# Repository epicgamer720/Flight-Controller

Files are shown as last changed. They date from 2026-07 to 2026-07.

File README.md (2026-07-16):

# Rocket Flight Controller

A custom, open-source flight computer for model and high-power rockets, built around an STM32F722 with onboard IMU, barometer, GPS, pyro deployment, quad servo outputs, and microSD logging. Designed from scratch in KiCad.

## Why I built it

Wanted to get my feet wet with more mixed PCB design. I designed this as a base for firmware and testing I plan to designing another one after I build and test this one on actual rockets. I plan to use this for my rocketry team for active control and data logging 

## Use cases

- **Dual-deploy recovery**: pyro drogue at apogee, then a servo mechanically releases the main at a set altitude. (This rev routes one pyro channel; the servo is the second deploy.)
- **Active stabilization**: drive the four servo outputs for thrust-vector control or canard/fin steering during boost.
- **Flight data logging**: log IMU, barometer, and GPS to microSD for post-flight analysis (apogee, max velocity, flight path).
- **GPS tracking**: downrange tracking and finding the rocket after landing.
- **Telemetry**: LoRa (SX1262, 915 MHz) for live altitude/position downlink.
- **General avionics dev board**: the IMU + baro + GPS + servo + logging combo also works for drones, RC, robotics, or balloon payloads.





## Specifications

| Subsystem | Part / detail |
|---|---|
| MCU | STM32F722RET6, Cortex-M7, up to 216 MHz |
| IMU | ISM330DHCX, 6-axis accel (±16 g) + gyro, SPI (built rev; early docs said ICM-45686) |
| Barometer | BMP580, altitude / apogee detection (I²C) |
| Storage | microSD (SDMMC1, 4-bit), 200 Hz binary flight log |
| Recovery | 1 pyro channel (gate PB13, continuity sense PC1) + servo main-release, giving dual-deploy without a 2nd pyro (2 designed) |
| Control | 4× servo outputs (TIM2) for TVC / fin / canard; one doubles as the main-release |
| GPS | NMEA module on USART6, JST-GH + PRTR5V0U2X ESD protection |
| Telemetry | LoRa Wio-SX1262 (915 MHz, TCXO): live downlink + over-air TX-power control, verified on hardware |
| Power | 2S LiPo, BQ25883 charger, USB-C |
| Status | WS2812 RGB status LED |

## Bench status (July 2026)

All subsystems green on hardware: IMU, barometer, SD logging, LoRa radio
(TCXO confirmed, telemetry transmitting), charger, GPS UART. The firmware
builds with `arm-none-eabi-gcc` (GitHub CI), has been flashed to the board,
and passes its on-console **preflight** GO/NO-GO check, so it is **bench-verified,
not flight-tested**. The deploy-critical logic is exercised host-side by a SIL
harness (a faithful Python transcription of the state machine / Kalman / pyro
paths) plus 245 stdlib-`unittest` tests, and went through several adversarial
multi-agent review passes.

Flight hardening on top of the earlier IWDG watchdog + reset-cause logging,
Kalman altitude filter with outlier gating, and pad-drift baro tracking:

- **Hardened arm gate**: refuses to arm without pyro continuity, adequate
  battery, near-zero velocity, *and* a plausible skyward orientation
  (`ARM_UP_AXIS`).
- **Fault-independent backup deploy**: a backup timer fires the charge even
  through `ST_FAULT` with dead sensors, so a sensor loss isn't a lawn-dart.
- **Servo dual-deploy**: a main-release servo held SAFE through ascent,
  actuated at the main-deploy altitude (no 2nd pyro needed).
- **Flash config v2**: runtime-tunable apogee/backup timer + last-GPS-for-
  recovery, migrating cleanly from v1.
- **Telemetry v3**: sequence / packet-delivery ratio, last-event echo,
  main-alt read-back, STM32 die-temp, and over-air TX-power control.
- Gyro-cal stationarity check, IMU-freeze detection, self-healing ground
  FAULT, failed-deploy detection, deeper anti-replay nonce window, baro
  temperature compensation, a recovery LED strobe (WS2812), and a STOP-mode
  low-power `sleep`.

**Tune before flight**: the defaults are placeholders, not final: `ARM_UP_AXIS`
(confirm the skyward IMU axis), the apogee/backup timer per motor (`apogee`
console cmd), the servo endpoints, and the flight thresholds (`LAUNCH_G`,
`MAIN_ALT`, debounces). The baro-only Kalman also lags true apogee by ~70 m in
SIL at `KAL_Q_ACCEL=4`, a candidate to raise once real flight data exists.
Also remaining: ground-station pin map + build, and a healthier USB cable.

## BOM

| Name | Purpose | Qty | Unit Cost (USD) | Line Cost (USD) | Link | Distributor | Notes |
|---|---|---|---|---|---|---|---|
| 1uF | Decoupling cap (0603, X7R, 25V) | 4 | $0.02 | $0.08 | Link | Digikey | |
| 10uF | Bulk decoupling (0805, X5R, 16V) | 7 | $0.10 | $0.40 | Link | Digikey | |
| 47nF | Filter cap, possibly BQ25883 ILIM or feedback (0603) | 1 | $0.02 | $0.02 | Link | Digikey | |
| 44uF | Unusual value, check schematic | 1 | $0.50 | $0.50 | Link | Digikey |  |
| 10uF | Bulk decoupling (0805, X5R) | 2 | $0.10 | $0.20 | Link | Digikey | |
| 22uF | Switching regulator output cap (0805, X5R, 16V) | 3 | $0.20 | $0.60 | Link | Digikey | |
| 100nF | Generic decoupling, 0402 or 0603 X7R | 12 | $0.01 | $0.12 | Link | Digikey | |
| 2.2uF | STM32 VCAP_1 (PA0) capacitor, 2.2µF X7R 0603 | 1 | $0.05 | $0.05 | Link | Digikey | Critical for MCU core regulator stability |
| 22uF | Regulator input/output cap | 2 | $0.20 | $0.40 | Link | Digikey | |
| 2.2uF | Second VCAP or filter | 1 | $0.05 | $0.05 | Link | Digikey | |
| 20pF | HSE crystal load capacitor (matches X322525MOB4SI) | 2 | $0.05 | $0.10 | Link | Digikey | Value depends on crystal CL spec, verify |
| 6.8pF | LSE 32.768kHz crystal load capacitor | 2 | $0.05 | $0.10 | Link | Digikey | Adjust to match crystal CL = ~7pF |
| 100nF | Generic decoupling, 0402 or 0603 | 5 | $0.01 | $0.05 | Link | Digikey | |
| TF-01A | MicroSD card socket (push-pull or hinged) | 1 | $1.50 | $1.50 | Link | LCSC | LCSC-style part; Hirose DM3AT-SF-PEJM5 is a Digikey alternative |
| LED | Generic indicator LED 0603 (e.g., power indicator) | 1 | $0.10 | $0.10 | Link | Digikey | |
| WS2812B-2020 | Addressable RGB status LED, single-wire (KMK-style) | 1 | $0.30 | $0.30 | Link | LCSC | Cheaper on LCSC than Digikey |
| PRTR5V0U2X | Dual-line TVS ESD protection for GPS UART | 1 | $0.35 | $0.35 | Link | Digikey | Nexperia, SOT-143B |
| Screw_Terminal_01x02 | 2-pin screw terminal for pyro outputs and battery | 3 | $1.20 | $3.60 | Link | Digikey | |
| BM05B-GHS-TBT_LF__SN__N_ | JST-GH 5-pin top-entry connector (GPS, Pixhawk standard) | 1 | $0.55 | $0.55 | Link | Digikey | JST part #BM05B-GHS-TBT(LF)(SN)(N) |
| FCM1608KF-601T03 | Ferrite bead 600Ω @ 100MHz, 0603, analog supply filter | 1 | $0.10 | $0.10 | Link | Digikey | Taiyo Yuden |
| DFE252012F-1R0M=P2 | Power inductor 1.0µH, 2520 case, buck output (LMR51430?) | 1 | $0.40 | $0.40 | Link | Digikey | Toko/Murata, ~3.6A saturation |
| XFL4020-152MEC | Power inductor 1.5µH, 4×4mm, switcher output | 1 | $1.50 | $1.50 | Link | Digikey | Coilcraft, very low DCR |
| YHNR3015-5R6M | Power inductor 5.6µH, likely buck-boost (TPS63070) | 1 | $0.30 | $0.30 | Link | LCSC | Sunlord, LCSC-stocked |
| AO3400A | N-channel logic-level MOSFET, SOT-23, pyro low-side switch | 2 | $0.15 | $0.30 | Link | Digikey | |
| 5.1K Ohm | Pullup/divider for USB-C CC1/CC2 (5.1k for device-mode detect) | 2 | $0.01 | $0.02 | Link | Digikey | Required for USB-C device mode |
| .383k Ohm | Precision resistor, likely BQ25883 ISET or regulator FB | 1 | $0.10 | $0.10 | Link | Digikey | |
| 5.23K Ohm | Feedback divider for switching regulator | 1 | $0.05 | $0.05 | Link | Digikey | 1% precision |
| 30.1K Ohm | Feedback divider (top resistor) for switching regulator | 1 | $0.05 | $0.05 | Link | Digikey | 1% precision |
| 10K Ohm | Generic pullups/pulldowns, gate pulldowns on MOSFETs (0603) | 19 | $0.01 | $0.19 | Link | Digikey | Cheap in bulk |
| 100K Ohm | Continuity divider top (pyro sense) | 1 | $0.01 | $0.01 | Link | Digikey | |
| 22.1K Ohm | Precision feedback or current-set resistor | 1 | $0.05 | $0.05 | Link | Digikey | 1% precision |
| 100K Ohm | More continuity dividers | 2 | $0.01 | $0.02 | Link | Digikey | |
| 100 Ohm | Gate series resistors on pyro MOSFETs | 3 | $0.01 | $0.03 | Link | Digikey | |
| Conn_01x03 | 3-pin header, likely servo/PWM outputs or programming | 4 | $0.30 | $1.20 | Link | Digikey | (2.54mm standard) |
| TS-1088-AR02016 | Tactile switch for boot/reset buttons | 2 | $0.20 | $0.40 | Link | Digikey | Cheap SMD tactile, also on LCSC |
| STM32F722RETx | Main MCU, ARM Cortex-M7, 216MHz, 512KB flash | 1 | $10.50 | $10.50 | Link | Digikey/Mouser | Check stock: F7 series can be supply-constrained |
| BQ25883RGER | Single-cell Li-ion charger w/ I2C, up to 2A | 1 | $3.80 | $3.80 | Link | Digikey | TI, QFN-24 |
| ICM-45686 | 6-axis IMU (accel + gyro), low-noise, SPI | 1 | $12.00 | $12.00 | Link | Digikey | TDK InvenSense, LGA-14. Newer than ICM-42688-P |
| BMP580 | Barometric pressure / altitude sensor (high resolution) | 1 | $4.20 | $4.20 | Link | Digikey | Bosch Sensortec, replaces BMP388 |
| TPS63070RNMR | Buck-boost regulator, 2A, 2-16V in | 1 | $3.60 | $3.60 | Link | Digikey | TI, VQFN-15 |
| LMR51430 | Buck regulator, 3A, simple step-down | 1 | $1.40 | $1.40 | Link | Digikey | TI, SOT-23-6 family |
| TYPE-C 16PIN 2MD(073) | USB-C connector, 16-pin (USB 2.0 only) | 1 | $0.50 | $0.50 | Link | LCSC | LCSC-style part number. Alt: GCT USB4105-GF-A (Digikey) |
| X322525MOB4SI | HSE crystal 25MHz, SMD 3225 | 1 | $0.60 | $0.60 | Link | LCSC | Yangxing. Alt: Abracon ABM8G-25.000MHZ |
| Q13FC1350000400 | LSE crystal 32.768kHz (RTC) | 1 | $0.40 | $0.40 | Link | Digikey | Epson FC-135 |

## Firmware & software

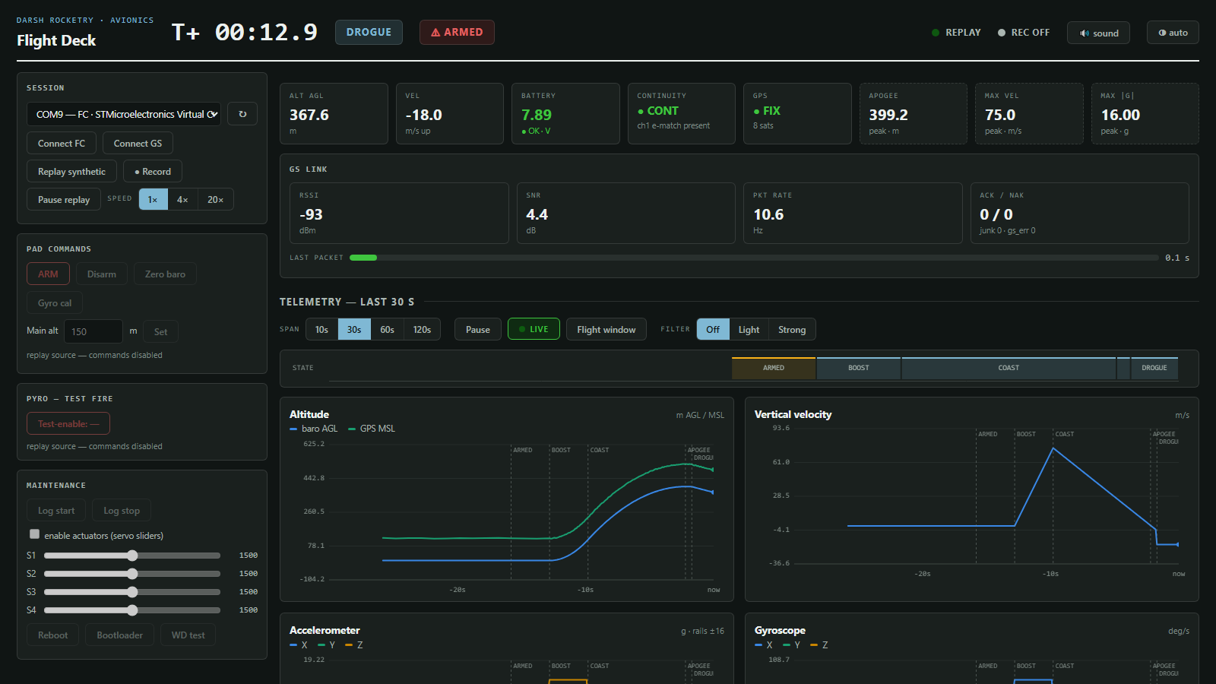
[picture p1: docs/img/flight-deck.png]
Flight Deck, the offline flight-ops dashboard, mid-flight on the synthetic profile


The flight firmware and ground tools live in this repo:

| Where | What |
|---|---|
| [`flight-controller/`](flight-controller/) | STM32F722 flight firmware: sensors, Kalman altitude filter, flight state machine, hardened arm gate + interlocked pyro control, fault-independent backup deploy, servo main-release, flash config v2, SD logging, LoRa telemetry v3 (die-temp + TX-power control), IWDG watchdog, USB console (`preflight`, `apogee`, `sleep`, …) |
| [`ground-station/`](ground-station/) | RP2040 + SX1262 LoRa ground station (RadioLib sketch; pin map pending) |
| [`shared/`](shared/) | `protocol.h`, the single source of truth for the radio link + packet formats |
| [`tools/`](tools/) | **Flight Deck** ops dashboard (recovery bearing/distance, baro-vs-GPS apogee check, telemetry-loss alarm, satellite GPS ground-track, SD `.bin` replay), one-page flight report, DFU flash helper (`flash.py`), serial monitor, log/telemetry decoders (`decode_log.py --summary`) |
| [`tests/`](tests/) | 245 host-side unit tests + a SIL flight harness (`py -m unittest discover -s tests`) |
| [`docs/FIRMWARE.md`](docs/FIRMWARE.md) | build / flash / console / bench guide |
| [`docs/PINMAP.md`](docs/PINMAP.md) | authoritative pin map extracted from the KiCad netlist |

## This project uses:

- [KiCad](https://www.kicad.org/)
- [STM32CubeMX](https://www.st.com/en/development-tools/stm32cubemx.html)
- [easyeda2kicad.py](https://github.com/uPesy/easyeda2kicad.py)
- [Hack Club Blueprint](https://blueprint.hackclub.com/)

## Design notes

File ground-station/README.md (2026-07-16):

# Ground Station (RP2040 + SX1262 + PE4259)

Compile-only skeleton of the ground-station firmware (CLAUDE.md §6):

- **RX**: IRQ-driven (DIO1) continuous LoRa receive of FC packets; each frame is
  validated (magic / version / CRC16-CCITT) and emitted as **one line of JSON**
  on USB-CDC Serial. Field names match `tools/telem_decode.py parse_telem()`
  output, plus `rssi` / `snr` from RadioLib.
- **TX**: operator commands typed on the same serial port become
  `command_packet_t` uplinks with a monotonically increasing, random-start
  nonce. Pad-only enforcement stays on the FC; the GS just sends.
- Link params and packet structs come **directly from `shared/protocol.h`**
  (single source of truth, §3/§7) via a `-I<repo>/shared` include flag.

```
ground-station/
  gs/
    gs.ino       sketch (Arduino-Pico + RadioLib)
    gs_pins.h    pin map: ALL -1 SENTINELS until extracted from the schematic
  README.md      this file
```

## 1. Install the toolchain

```sh
# arduino-cli: https://arduino.github.io/arduino-cli/latest/installation/
#   Windows: download the .zip, put arduino-cli.exe on PATH
#   (or: winget install ArduinoSA.CLI)

arduino-cli config init
arduino-cli config add board_manager.additional_urls \
  https://github.com/earlephilhower/arduino-pico/releases/download/global/package_rp2040_index.json
arduino-cli core update-index
arduino-cli core install rp2040:rp2040     # Earle Philhower Arduino-Pico core
arduino-cli lib install RadioLib           # SX1262 driver (6.x/7.x API used)
```

## 2. Compile

Run from the repo root (`C:\Users\14437\OneDrive\Desktop\flight controller`).
The repo path contains a **space**, so the `-I` flag needs quoting at *two*
levels: your shell must hand arduino-cli the literal value

```
compiler.cpp.extra_flags=-I"C:/Users/14437/OneDrive/Desktop/flight controller/shared"
```

as **one argument with the inner double quotes intact**, because arduino-cli splits
the expanded compiler recipe on spaces *except inside double quotes*, so the
inner quotes are what keep the path together as a single `-I` argument to gcc.
(Use forward slashes: a trailing `shared\"` backslash would escape the quote.)

**Git Bash** (`\` line continuations are bash-only; for cmd.exe use `^` or put
it all on one line):

```sh
arduino-cli compile -b rp2040:rp2040:rpipico --warnings default \
  --build-property "compiler.cpp.extra_flags=-I\"C:/Users/14437/OneDrive/Desktop/flight controller/shared\"" \
  --output-dir ground-station/gs/build \
  ground-station/gs
```

**PowerShell 5.1** (does *not* escape embedded quotes for native commands, so
they must be backslash-escaped manually even inside single quotes):

```powershell
arduino-cli compile -b rp2040:rp2040:rpipico --warnings default `
  --build-property 'compiler.cpp.extra_flags=-I\"C:/Users/14437/OneDrive/Desktop/flight controller/shared\"' `
  --output-dir ground-station\gs\build `
  ground-station\gs
```

> `--warnings default` matters: arduino-cli's default warning level is `none`,
> which compiles with `-w` and **silently suppresses the intentional
> `#warning`** in `gs_pins.h`. Without it the only pin-sentinel guard you'll
> see is the runtime `{"error": ...}` refusal on the serial port.

> Quoting rationale worked out from arduino-cli's recipe splitter + PS 5.1
> native-argument rules; **not yet verified by an actual compile**, since arduino-cli
> was not installed on this machine when the skeleton was written. If the build
> fails with `cannot find protocol.h` or gcc sees `controller/shared"` as an
> input file, the quoting was mangled by the shell; try the other shell's form.

**Expected output**: the build **succeeds** but prints

```
warning: gs_pins.h: pin map not yet extracted from the GS KiCad schematic ...
```

That `#warning` is intentional (see §5) and stays until `gs_pins.h` is filled in.

## 3. Flash

**BOOTSEL (no tools needed):** hold the BOOTSEL button while plugging in USB;
a `RPI-RP2` drive appears; copy `ground-station/gs/build/gs.ino.uf2` onto it.
The board reboots into the firmware.

**picotool:**

```sh
picotool load -f ground-station/gs/build/gs.ino.uf2
picotool reboot
```

## 4. Use

Open the USB-CDC serial port (any baud; e.g. 115200). Output is line-delimited
JSON: one object per received packet (telemetry / event / ack, keyed by
`type`), or `{"error": ...}` lines for CRC/length failures and status.

Commands (one per line, newline-terminated):

| Command | Uplink | `arg` encoding | FC-side gate |
|---|---|---|---|
| `arm` | CMD_ARM | 0 | pad + sensors healthy |
| `disarm` | CMD_DISARM | 0 | none |
| `mainalt <m>` | CMD_SET_MAIN_ALT | meters × 100 (cm), 30–2000 m | refused while armed; persisted to flash |
| `zero` | CMD_ZERO_BARO | 0 | pad only |
| `reboot` | CMD_REBOOT | 0 | none |
| `fire <ch> <hexcode>` | CMD_TEST_FIRE | `passcode<<16 \| channel` | ST_GROUND_IDLE + disarmed + `testen` + passcode + fresh nonce |
| `nop` | CMD_NOP | 0 | none |
| `help` | (local) | none | none |

Each uplink is transmitted **once** and reported as an `{"uplink": ...}` JSON
line with the nonce and RadioLib TX status; the FC's ACK (a 46-byte frame with
`type` = 0x11) shows up as a normal JSON line when it arrives. Uplinks only
land while the FC is on the pad. In flight the FC is TX-only (§4) and the
command is simply lost (resend from the pad).

## 5. What is blocked, and how to unblock

Hardware bring-up is **blocked** on two things (compile is not):

1. **GS pin map extraction**: every pin in `gs/gs_pins.h` is a `-1` sentinel.
   Per CLAUDE.md §0 the KiCad schematic is the source of truth and GPIO numbers
   must never be guessed. *Unblock*: parse the GS `.kicad_sch` / netlist,
   fill in NSS / DIO1 / NRESET / BUSY / SCK / MOSI / MISO (RP2040 GPIO
   numbers), confirm the pins land on one SPI block (`SPI` vs `SPI1`, see the
   comment in `gs_pins.h`), and set `GS_RADIO_TCXO` (0 = XTAL, 1 = TCXO via
   DIO3) from the schematic; the current 0 is a placeholder, not an answer.
   Rebuild; the `#warning` disappears and the runtime refusal loop lifts.
2. **FC radio hardware**: the flight controller currently reports `radio=0`
   on the bench (see `radiodbg` console triage). Until the FC's SX1262
   transmits, the GS has nothing to receive. *Unblock*: fix/verify the FC
   radio, then confirm the link with the FC on pad cadence (1 Hz).

Also before range tests: verify +22 dBm at 915 MHz against regulatory limits
(CLAUDE.md §10).

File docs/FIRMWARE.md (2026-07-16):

# Rocketry Avionics: bench quickstart

Flight controller firmware for an **STM32F722RET6** board (`flight-controller/`) plus a
planned **RP2040 ground station**, linked over **915 MHz LoRa** (SX1262 on both ends).
`shared/protocol.h` is the wire contract for both boards; `CLAUDE.md` has the full
design context and safety rules; `docs/PINMAP.md` is the authoritative pin map.

> **Status:** SIL/host-tested, builds clean, and flashed + bench-verified on hardware,
> but **not yet flight-tested.** Flight thresholds in `App/app_config.h` are still defaults;
> tune them (and the mount knobs flagged below) to the motor/airframe before flying.

## Build

No SWD on this board, so everything goes through USB (CDC console + DFU flashing).

```
cd flight-controller
C:/Users/14437/toolchains/build-tools/bin/make.exe -j GCC_PATH=C:/Users/14437/toolchains/arm-gcc/bin
```

Outputs `build/fc.elf`, `build/fc.hex`, `build/fc.bin`.

## Flash (USB DFU)

1. Enter the bootloader: type `bootloader` on the console, **or** hold BOOT (SW2),
   tap RESET (SW1), release BOOT.
2. Flash:

```
dfu-util -l                                              # should list 0483:df11
dfu-util -a 0 -d 0483:df11 -s 0x08000000:leave -D build/fc.bin
```

If dfu-util says **"cannot open"**: unplug USB and replug it *while holding BOOT*.
(`STM32_Programmer_CLI -c port=usb1 -w build\fc.bin 0x08000000 -v -g 0x08000000`
works too; see `docs/PINMAP.md`.)

## Console commands

115200-8N1 USB-CDC (baud ignored). The authoritative list is `help` on the board
(`App/console.c`, `cmd_help`); snapshot:

| Command | Does |
|---|---|
| `help` | command list |
| `status` | state / armed / alt / vel / batt / **MCU die-temp** / flags / health / pyro |
| `preflight` | GO/NO-GO checklist before arming (read-only, nothing is pulsed) |
| `sensors` | raw IMU + baro |
| `gps` | last GPS fix + persisted last-landing fix |
| `servo <1-4> <500-2500>` | set servo pulse (µs) |
| `arm` / `disarm` | arming gate (prints refusal code `-1`..`-8`) / disarm |
| `testen <on\|off>` | pad test mode (GROUND_IDLE only; always boots **off**) |
| `fire <ch> <hex-code>` | pad test fire (testen + passcode gated) |
| `zero` | zero baro AGL |
| `mainalt <m>` | set main deploy altitude (persisted to flash) |
| `apogee <ms>` | set apogee / backup-deploy timer (per-motor); persisted to flash |
| `log <stat\|start\|stop>` | SD logging (stat shows drops + ring high-water) |
| `cal` | pad gyro bias cal (~2 s, keep still; rejected if it moves) |
| `radio` | radio health + re-init / TX-timeout counters |
| `radiodbg` | raw SX1262 hardware probe (BUSY/reset/SPI bytes) |
| `tx [power\|mon\|cw\|frame]` | TX dashboard; set power / packet monitor / bench CW / force a frame |
| `i2cscan` | scan I2C1 for devices |
| `charge` | BQ25883 charger status |
| `bootloader` | reboot into USB DFU |
| `reboot` | reset MCU |
| `wdtest` | deliberate hang; IWDG must reset the board in ~4 s |
| `sleep [s]` | STOP-mode low power (ground + disarmed); wakes on RTC timer or RESET; 0/none = until RESET |

## Tools (`tools/`)

`py -m pip install -r requirements.txt` (pyserial for the serial tools, pywebview for Flight Deck's native window).

| Tool | Use |
|---|---|
| `py tools/flight_deck.py` | **Flight Deck**, the flight-ops dashboard (see below) |
| `py tools/serial_monitor.py` | timestamped console; auto-detects the FC COM port (`--list`, `--port COM7`) |
| `py tools/live_dashboard.py [--port COM9] [--http 8321]` | simple bring-up charts at http://localhost:8321. **Owns the COM port while running**, so stop it before serial_monitor or flashing |
| `py tools/decode_log.py LOG001.BIN [out.csv]` | SD binary log → CSV (68-B records, CRC-checked, resyncs past corruption) |
| `py tools/telem_decode.py <hex>` | parse/build LoRa packets from `shared/protocol.h`; importable by the GS bridge |

## Flight Deck (`tools/flight_deck.py`)

Offline mission-control app in a native window (pywebview/WebView2; `--browser`
falls back to the default browser). Fully local: 127.0.0.1 only.

```
py tools/flight_deck.py                          # FC over USB, auto-detects the port
py tools/flight_deck.py --source gs --port COM7  # ground-station JSON bridge
py tools/flight_deck.py --source replay --synthetic --speed 4   # no hardware needed
py tools/flight_deck.py --source replay --replay recordings/deck_.../raw.jsonl
```

- **Instruments**: T+ clock (starts at BOOST), state timeline, alt/vel/accel/
  gyro/battery charts with labeled event markers + pan/zoom/pause + flight-window
  button, peak tiles (apogee, max vel, max |g|), continuity/battery/GPS tiles,
  GS link panel (RSSI/SNR/packet rate/gap/ACK-NAK), scrolling event log with
  verbatim firmware refusals, audio alerts (state, FAULT, low battery), theme
  toggle.
- **Commands** are interlocked in the UI *and* re-checked by the firmware (the
  firmware is always the real gate): arm/disarm confirmations, mainalt bounded
  30–2000 m (the radio path's stricter bound), test-fire behind test-enable →
  passcode (never stored, never logged; masked even in recordings) → 2 s
  hold-to-fire. In flight the FC is TX-only, so every command control disables
  itself with the reason shown.
- **Recording**: each live session writes `recordings/deck_<stamp>/telem.csv` +
  `events.csv` (+ lossless `raw.jsonl` on GS sessions); replay any of them with
  `--source replay --replay <file>`. FC sessions are poll-rate on the ground;
  the FC's own 200 Hz SD log remains the authoritative flight record.
- **Owns its COM port** while running (like live_dashboard). It closes the port
  on every exit path; if a hard-killed host process ever wedges the FC's USB
  console (port opens but no replies), tap RESET or replug USB.

## Tests

```
py -m unittest discover -s tests
```

Stdlib-only: CRC16 golden vectors, log-record decode/resync, telemetry packet
round-trips, a Python port of the Kalman gate, and a console↔dashboard contract
test that fails loudly if `App/console.c` output drifts from what
`tools/live_dashboard.py` scrapes.

## BOR option byte (one-time, manual)

```
# board in DFU mode first (BOOT + RESET)
STM32_Programmer_CLI -c port=usb1 -ob displ          # check current BOR_LEV first
STM32_Programmer_CLI -c port=usb1 -ob BOR_LEV=0      # 0b00 = BOR Level 3 ≈ 2.7 V
```

Sets brown-out reset to ~2.7 V. **The F7 encoding is inverted-looking** (RM0431,
FLASH_OPTCR bits 3:2): value **0 = Level 3 (~2.7 V)** … value **3 = BOR off**,
which is also the shipping default, so a fresh chip displays `BOR_LEV: 0x3`.
Without it, a battery sag or pyro-fire droop can leave the F7 running erratically
(corrupting flash/SD writes) instead of resetting cleanly. Option bytes live
outside program flash, so this survives reflashing; do it once per board.

## Safety & flight logic

Every pyro decision is made in `App/state_machine.c` and only there: radio commands can
never fire in flight (CLAUDE.md §2). Not flight-tested yet; the thresholds are defaults.

- **Arming gate** (`fsm_request_arm`) requires *all* of: `ST_GROUND_IDLE`, IMU + baro
  healthy, gyro cal done, near-zero velocity, plausible |accel|, **pyro continuity**,
  **battery ≥ `ARM_MIN_VBAT_MV` (7.0 V)**, and **vertical orientation**. On refusal it
  returns a code the console prints in English: `-1` not idle, `-2` imu/baro, `-3` gyro
  cal, `-4` moving, `-5` accel implausible, `-6` no pyro continuity, `-7` battery low,
  `-8` not vertical. Orientation keys off `ARM_UP_AXIS`/`ARM_UP_SIGN` (default +Z, a
  **mount knob**); a wrong axis safely *refuses* with `-8`, it never misfires. `preflight`
  shows the same checks as a GO/NO-GO list without arming.
- **Fault-independent backup deploy**: once launched, the single charge fires at
  `apogee_timeout_ms` after launch **even in `ST_FAULT`** with dead sensors: it bypasses
  the armed gate through one controlled path (`pyro_fire_backup`). Fires at most once,
  never on the pad and never after landing; a deploy pulse is aborted **only** by a ground
  disarm, never truncated by an in-flight fault. This is the anti-lawn-dart last line; set
  `apogee` to just past expected apogee per motor (clamped to `[MAX_BURN_MS, 120000]` so it
  can't fire under thrust).
- **Servo main-release** (this board has one pyro channel, fired at apogee; a servo releases
  the main): held SAFE through all ascent and through `ST_FAULT`, released only at the guarded
  DROGUE→MAIN point (descending AND AGL ≤ `main_alt`, upward velocity inhibited). Parked SAFE
  at boot before the first control pass. `SERVO_SAFE_US`/`SERVO_RELEASE_US` are **mount knobs**.
- **Sensor guards**: gyro cal is rejected if the vehicle moves during it (per-axis gyro
  peak-to-peak + accel-stray band → auto-restart, so a bad bias never latches); IMU reads
  detect a frozen/stuck bus (rail bytes, or N byte-identical bursts) and fail, tripping the
  0.5 s IMU-fail debounce → `ST_FAULT`; baro altitude is temperature-compensated (pad temp
  latched at `zero`).
- **Fault handling**: a *ground* fault (never launched) self-heals back to `ST_INIT` once
  both sensors read healthy again (re-runs gyro cal + baro zero); any *in-flight* fault
  latches: logging + telemetry keep running, pyros safe, the backup timer still armed.
- **Anti-replay**: 32-deep nonce dedup ring with **no** monotonic floor. The GS reseeds its
  nonce randomly on restart, so a floor would permanently lock out a restarted GS.

## Firmware notes

- **IWDG ~4 s** is armed at the end of init and refreshed once per superloop pass;
  any hang reboots the MCU (reset cause is printed in the boot banner). `wdtest`
  proves it end-to-end.
- **Config persists** in flash **sector 7 @ `0x08060000`** (append-record store **v2**,
  `App/param_store.c`): 28-byte slots holding `main_alt`, the runtime `apogee_timeout`,
  and the last landing GPS fix (recovery aid). Migrates cleanly from the old 16-byte v1
  (mismatched records are skipped, then appended past). Code flash is capped at **384 KB**
  in the linker so an oversized image fails at link instead of clobbering the store.
  **Never persisted** by design: `testen` (boots off), gyro bias, baro zero; all re-done
  each pad session.
- **Telemetry is protocol v3** (`PROTO_VERSION 3`, 54-byte `telem_packet_t` in
  `shared/protocol.h`): per-frame `seq` (host computes packet-delivery ratio), a last-event
  echo (`last_evt_state` + `last_evt_count`, so a dropped `PKT_EVENT` still surfaces), and a
  `main_alt` read-back; plus `FLAG_LOW_BATT` and `FLAG_DEPLOY_FAIL` status bits. FC and GS
  must compile the same `protocol.h`. `CMD_SET_TX_POWER` sets TX power over the air (pad-only,
  like every uplink command).
- **64 KB SD log ring** (~4.8 s of 200 Hz records); `log stat` reports drops and
  ring high-water.
- `log start` failure codes: `-1` no card, `-2` link, `-3` mount, `-4` scan,
  `-5` slots, `-6`/`-7` open.

## Status LED legend (WS2812 on PC13, needs the 5 V rail)

| State | Color |
|---|---|
| INIT | dim white |
| GROUND_IDLE | rainbow cycle with GPS fix, dim green without; red if armed |
| ARMED | solid red |
| BOOST / COAST | magenta |
| APOGEE / DROGUE | cyan |
| MAIN / DESCENT | amber |
| LANDED | bright green recovery strobe (~1/s) |
| FAULT | bright red recovery strobe (~1/s) |
| SD not logging | blue flash once per second (overlays any state) |

Bench test (console, pad + disarmed only): `led <r> <g> <b>` shows a raw
color for 5 s; `led bright <0-100>` sets a global brightness scale (all
patterns, persists until reboot); `led cycle [period_ms]` steps through
every flight state so you can preview the mapping above; `led state
<name|0-10>` holds on one specific state's pattern (e.g. `led state
LANDED`); `led effect solid|blink|breathe|strobe <r> <g> <b> [period_ms]`
and `led effect rainbow [period_ms]` run a bench-only pattern; `led auto`
/ `led effect off` resumes the real flight-state pattern. Arming
force-clears any active test/effect so it can never mask the ARMED
indicator. Flight Deck (`tools/flight_deck.py`) exposes all of these as
a Status LED bench panel when connected over USB.

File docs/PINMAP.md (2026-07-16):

# Flight Controller pin map (authoritative)

Source: `C:\Users\14437\Downloads\fe\Flight controler.kicad_sch`, netlist exported
2026-07-07 with `kicad-cli sch export netlist --format kicadxml`. This resolves all
`TODO` rows in CLAUDE.md §5.2. The board's IMU is **ISM330DHCX** (matches CLAUDE.md;
the December 2025 board rev in `Desktop\Flight-Controller` used ICM-45686 + no radio;
that rev is obsolete).

| Function | Pin | Notes |
|---|---|---|
| IMU ISM330DHCX CS | PA4 | 10K pull-up (R23) |
| SPI1 SCK / MISO / MOSI | PA5 / PA6 / PA7 | shared IMU + LoRa, mode 0, 6.75 MHz |
| IMU INT1 / INT2 | PC4 / PB0 | inputs (polled) |
| LoRa Wio-SX1262 CS | PA9 | 10K pull-up (R24) |
| LoRa DIO1 (IRQ) | PA10 | EXTI15_10, rising |
| LoRa BUSY | PB1 | input |
| LoRa NRESET | PA15 | output, active low |
| LoRa RF_SW1 | PB2 | **keep high-Z (analog)**, driven by module DIO2 |
| Barometer BMP580 | I2C1 PB6/PB7 | 4.7K pull-ups; INT = PB9; addr 0x46/0x47 |
| Charger BQ25883 | I2C1 PB6/PB7 | addr 0x6B; INT = PB5 (10K PU); ~CE = PB8 (low = charge) |
| GPS (JST-GH J8) | USART6 TX=PC6 RX=PC7 | PPS = PA8; ESD PRTR5V0U2X; ext. module |
| Pyro 1 gate | **PB13** | AO3400A low-side (Q2); 100R gate R, 10K pulldown; **boot LOW** |
| Pyro 1 continuity | **PC1** = ADC123_IN11 | divider 100K(R29)/10K(R30) from J7.2; VBAT/11 when continuous |
| Pyro terminal | J7 | J7.1 = BAT+, J7.2 = FET drain |
| (dangling) | PC0 | schematic label `PYRO_CON_1` unrouted, unused |
| Servo 1–4 | PA0/PA1/PA2/PA3 | TIM2 CH1–4, AF1, 50 Hz |
| SD card | SDMMC1 4-bit | D0=PC8 D1=PC9 D2=PC10 D3=PC11 CLK=PC12 CMD=PD2 (all 10K PU) |
| SD card detect | PB3 | internal pull-up, LOW = card present |
| USB-C | PA11=DM PA12=DP | device (5.1K CC pulldowns); **PA9 VBUS sensing OFF** (PA9 = LoRa CS!) |
| Status LED WS2812B-2020 | PC13 | via 100R; PC13 is low-drive, so it's bit-banged, best-effort |
| Buttons | SW1=NRST, SW2=BOOT0 | BOOT0 + reset = USB DFU bootloader |
| HSE / LSE | PH0/PH1 25 MHz, PC14/PC15 32.768 kHz | |
| Battery sense | n/a | none to MCU; read VBAT via BQ25883 ADC (I2C) |
| SWD | PA13/PA14 | unconnected (DFU + USB console only) |

## Clocks
216 MHz SYSCLK (HSE 25 MHz, PLLM=25 N=432 P=2), overdrive, APB1 54 MHz, APB2 108 MHz,
PLLQ=9 → 48 MHz for USB + SDMMC.

## Flash procedure (Windows, this machine)
```
# board in DFU: hold BOOT (SW2), tap RESET (SW1), release BOOT (enumerates 0483:DF11)
cd flight-controller
C:\Users\14437\toolchains\build-tools\bin\make.exe -j GCC_PATH=C:\Users\14437\toolchains\arm-gcc\bin
& "C:\Program Files\STMicroelectronics\STM32Cube\STM32CubeProgrammer\bin\STM32_Programmer_CLI.exe" `
    -c port=usb1 -w build\fc.bin 0x08000000 -v -g 0x08000000
```
Software re-entry: `bootloader` command on the USB console (or CMD_ENTER_BOOTLOADER).

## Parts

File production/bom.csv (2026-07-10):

Designator | Footprint | Quantity | Value | LCSC Part #
BOOT, RESET | SW-SMD_L3.9-W3.0-P4.45 | 2 | TS-1088-AR02016 | C720477
C1, C28, C29, C30 | 0402 | 4 | 1uF
C10, C11, C13 | 0805 | 3 | 22uF
C12, C2, C9 | 0603 | 3 | 10uF
C14, C15, C19, C20, C21, C22, C23, C24, C25, C26, C27, C37 | 0201 | 12 | 100nF
C16 | 0603 | 1 | 2.2uF
C17, C18 | 0402 | 2 | 22uF
C3, C31, C5 | 0402 | 3 | 10uF
C32 | 0201 | 1 | 2.2uF
C33, C34 | 0201 | 2 | 20pF
C35, C36 | 0201 | 2 | 6.8pF
C4 | 0201 | 1 | 47nF
C6 | 0603 | 1 | 44uF
C7, C8 | 0805 | 2 | 10uF
CARD1 | TF-SMD_TF-01A | 1 | TF-01A | C91145
D1 | 0402 | 1 | LED
J1 | TerminalBlock_Xinya_XY308-2.54-2P_1x02_P2.54mm_Horizontal | 1 | Screw_Terminal_01x02
J2, J3 | PinHeader_1x03_P2.54mm_Vertical | 2 | Conn_01x03
L4 | L0603 | 1 | FCM1608KF-601T03 | C141723
L5 | L2520 | 1 | DFE252012F-1R0M=P2 | C435392
L6 | IND-SMD_L4.0-W4.0-A | 1 | XFL4020-152MEC | C3033018
L7 | IND-SMD_L3.0-W3.0 | 1 | YHNR3015-5R6M | C18236327
R1, R2 | 0201 | 2 | 5.1K
R10, R11, R12, R13, R16, R17, R18, R19, R20, R21, R22, R6, R7, R8, R9 | 0201 | 15 | 10K
R14 | 0402 | 1 | 100K
R15 | 0402 | 1 | 22.1K
R3 | 0201 | 1 | 383
R4 | 0201 | 1 | 5.23K
R5 | 0201 | 1 | 30.1K
U1 | LQFP-64_10x10mm_P0.5mm | 1 | STM32F722RETx
U2 | VFQFPN-24_L4.0-W4.0-P0.50-BL-EP2.8 | 1 | BQ25883RGER | C544362
U3 | LGA-14_L3.0-W2.5-P0.50-TL | 1 | ICM-45686 | C22459454
U4 | LGA-10_L2.0-W2.0-P0.50-TL_BMP580 | 1 | BMP580 | C22391138
U5 | VQFN-HR-15_L3.0-W2.5-P0.50-BL_TPS63070RNMR | 1 | TPS63070RNMR | C109322
U6 | SOT-23-6 | 1 | LMR51430
USB1 | USB-C-SMD_TYPE-C-6PIN-2MD-073 | 1 | TYPE-C 16PIN 2MD(073) | C2765186
X1 | CRYSTAL-SMD_4P-L3.2-W2.5-BL | 1 | X322525MOB4SI | C9006
X2 | FC-135R_L3.2-W1.5 | 1 | Q13FC1350000400 | C32346

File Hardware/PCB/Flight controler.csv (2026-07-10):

Qty | Value
4 | 1uF
4 | 10uF
3 | 10uF
1 | 47nF
1 | 44uF
2 | 10uF
3 | 22uF
12 | 100nF
1 | 2.2uF
2 | 22uF
1 | 2.2uF
2 | 20pF
2 | 6.8pF
5 | 100nf
1 | TF-01A
1 | LED
1 | WS2812B-2020
1 | PRTR5V0U2X
3 | Screw_Terminal_01x02
1 | BM05B-GHS-TBT_LF__SN__N_
1 | FCM1608KF-601T03
1 | DFE252012F-1R0M=P2
1 | XFL4020-152MEC
1 | YHNR3015-5R6M
2 | AO3400A
2 | 5.1K
1 | .383k
1 | 5.23K
1 | 30.1K
19 | 10K
1 | 100K
1 | 22.1K
2 | 100K
3 | 100
4 | Conn_01x03
2 | TS-1088-AR02016
1 | STM32F722RETx
1 | BQ25883RGER
1 | ICM-45686
1 | BMP580
1 | TPS63070RNMR
1 | LMR51430
1 | TYPE-C 16PIN 2MD(073)
1 | X322525MOB4SI
1 | Q13FC1350000400

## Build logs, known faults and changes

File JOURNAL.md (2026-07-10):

<!--
  This journal is auto generated by Stasis.
-->

# 5/17/2026 5 PM - Decided to add a few things to get me to 17 hours

_Time spent: 2h_

I added a JST for GPS with a PRTR5V0U2X to help a bit with noise also added 2 pyrochanels and a status LED not sure why I didnt put one before but all pretty simple adds I also took advantage of the back of the PCB when I was placing and routing made my life alot easier.











# 12/29/2025 12 PM - I finished the PCB

_Time spent: 4h_

I finished the PCB and it looks great I double and triple checked literally everything but I locked it and I had zero issues. I did ocd it a little and I was making sure all the traces where evenly spaced but super excited.







# 12/28/2025 9 PM - Routed Part of the PCB

_Time spent: 2h_

Organized into the size I wanted and also started routing everything not done yet though, I struggled a little bit with some of the traces because I forgot to change the clearance but after I figured it out it was smooth sailing.





# 12/28/2025 1 PM - Finished organizing everything

_Time spent: 1.5h_

I finished organizing all of the components into there groups to make it easier later I had no trouble this part I actually kinda enjoyed it I also put everything in groups





# 12/28/2025 1 PM - Finished organizing everything

_Time spent: 1.5h_

I finished organizing all of the components into there groups to make it easier later I had no trouble this part I actually kinda enjoyed it I also put everything in groups





# 12/28/2025 2 AM - Started PCB design

_Time spent: 1.5h_

started the actual PCB design, currently I am in the organization stage putting the decoupling resistors and caps where they need to go as close as possible. Had a little bit of trouble because the microSD card footprint wasn't showing up but I figured it out!





# 12/27/2025 11 PM - Finished schematic design

_Time spent: 2h_

I finished the schematic design and started assigning footprints, I had a little bit of trouble finding the right inductors and caps but I found the eventually





# 12/27/2025 6 PM - Started schematic design

_Time spent: 2.5h_

I started the schematic design for the controller and I installed the easyeda2kicad library to make it easier I also learned how to pick out parts and look at a data sheet and design a schematic from it. I have trouble installing the library but I figured it out eventually  





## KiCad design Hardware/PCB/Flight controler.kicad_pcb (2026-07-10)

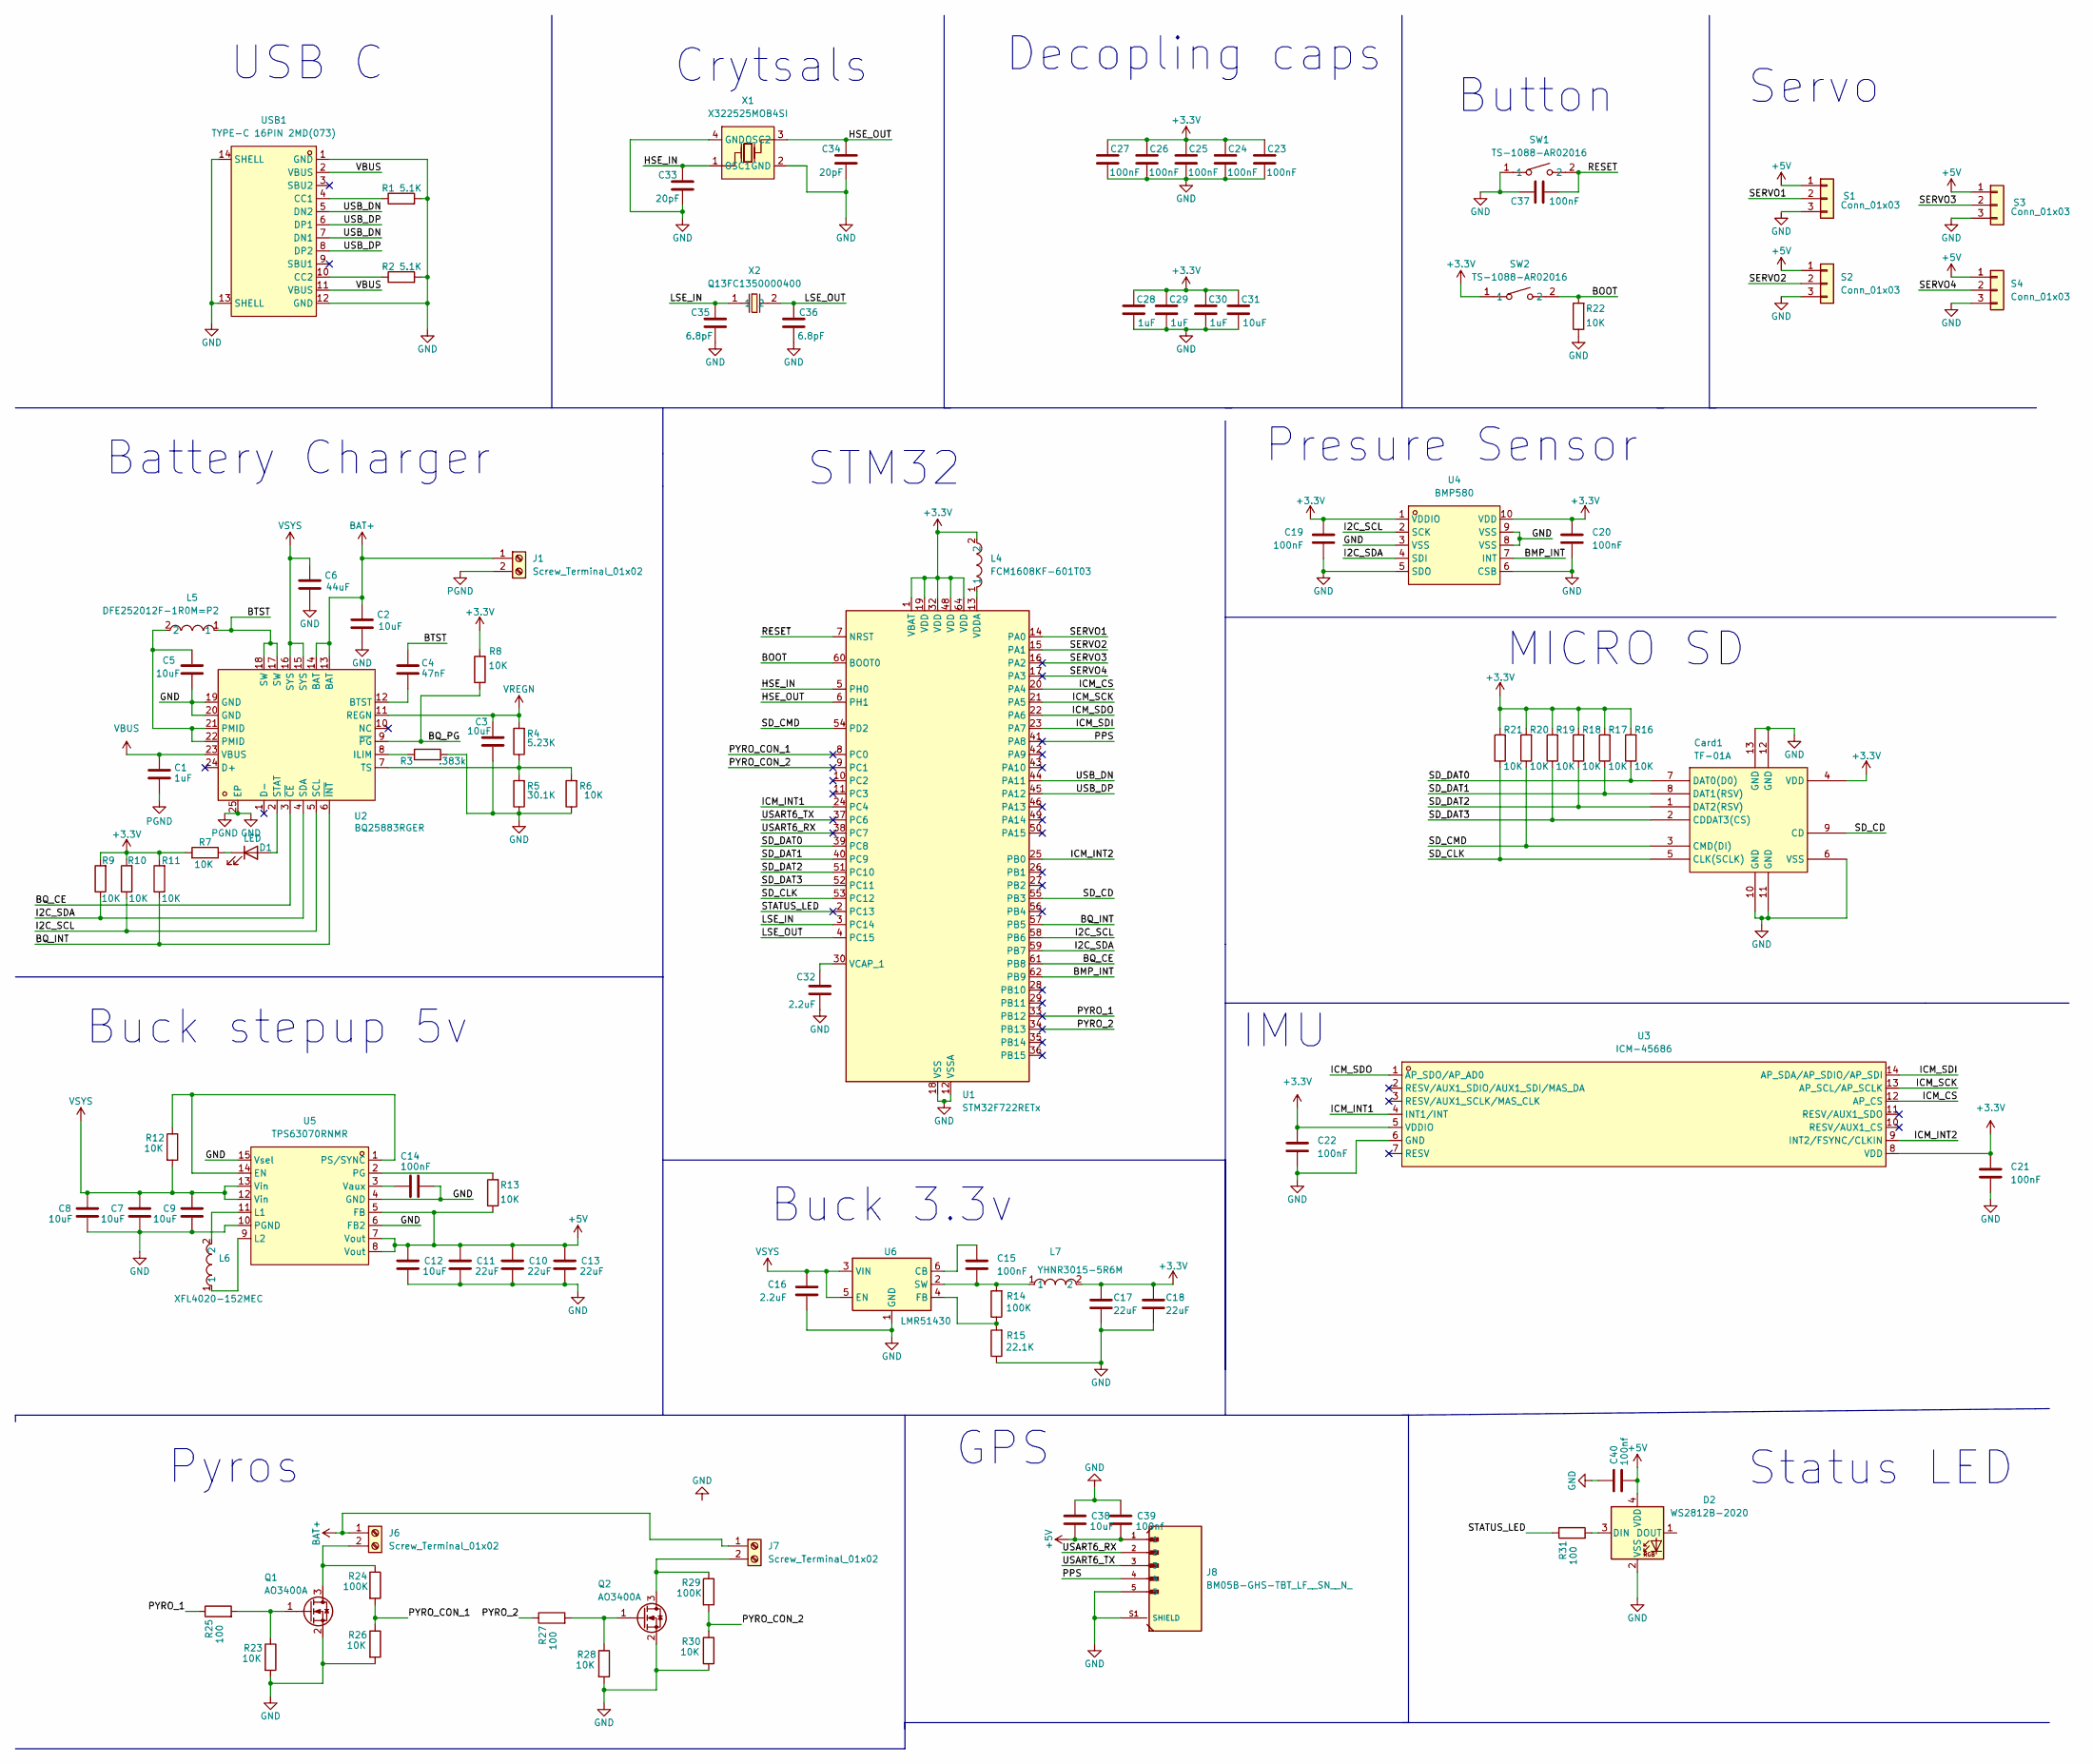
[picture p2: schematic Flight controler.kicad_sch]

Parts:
C1, C28, C29, C30: 1uF; C_0402_1005Metric
C2, C9, C12, C38: 10uF; C_0603_1608Metric
C3, C5, C31: 10uF; C_0402_1005Metric
C4: 47nF; C_0201_0603Metric
C6: 44uF; C_0603_1608Metric
C7, C8: 10uF; C_0805_2012Metric
C10, C11, C13: 22uF; C_0805_2012Metric
C14, C15, C19, C20, C21, C22, C23, C24, C25, C26, C27, C37: 100nF; C_0201_0603Metric
C16: 2.2uF; C_0603_1608Metric
C17, C18: 22uF; C_0402_1005Metric
C32: 2.2uF; C_0201_0603Metric
C33, C34: 20pF; C_0201_0603Metric
C35, C36: 6.8pF; C_0201_0603Metric
C39, C40: 100nf; C_0603_1608Metric
Card1: TF-01A; TF-SMD_TF-01A; LCSC Part C91145
D1: LED; LED_0402_1005Metric
D2: WS2812B-2020; LED_WS2812B-2020_PLCC4_2.0x2.0mm
J1, J6, J7: Screw_Terminal_01x02; TerminalBlock_Xinya_XY308-2.54-2P_1x02_P2.54mm_Horizontal
J8: BM05B-GHS-TBT_LF__SN__N_; JST_BM05B-GHS-TBT_LF__SN__N_
L4: FCM1608KF-601T03; L0603; LCSC Part C141723
L5: DFE252012F-1R0M=P2; L2520; LCSC Part C435392
L6: XFL4020-152MEC; IND-SMD_L4.0-W4.0-A; LCSC Part C3033018
L7: YHNR3015-5R6M; IND-SMD_L3.0-W3.0; LCSC Part C18236327
Q1, Q2: AO3400A; SOT-23
R1, R2: 5.1K; R_0201_0603Metric
R3: .383k; R_0201_0603Metric
R4: 5.23K; R_0201_0603Metric
R5: 30.1K; R_0201_0603Metric
R6, R7, R8, R9, R10, R11, R12, R13, R16, R17, R18, R19, R20, R21, R22, R23, R26, R28, R30: 10K; R_0201_0603Metric
R14: 100K; R_0402_1005Metric
R15: 22.1K; R_0402_1005Metric
R24, R29: 100K; R_0201_0603Metric
R25, R27, R31: 100; R_0201_0603Metric
S1, S2, S3, S4: Conn_01x03; PinHeader_1x03_P2.54mm_Vertical
SW1, SW2: TS-1088-AR02016; SW-SMD_L3.9-W3.0-P4.45; LCSC Part C720477
U1: STM32F722RETx; LQFP-64_10x10mm_P0.5mm
U2: BQ25883RGER; VFQFPN-24_L4.0-W4.0-P0.50-BL-EP2.8; LCSC Part C544362
U3: ICM-45686; LGA-14_L3.0-W2.5-P0.50-TL; LCSC Part C22459454
U4: BMP580; LGA-10_L2.0-W2.0-P0.50-TL_BMP580; LCSC Part C22391138
U5: TPS63070RNMR; VQFN-HR-15_L3.0-W2.5-P0.50-BL_TPS63070RNMR; LCSC Part C109322
U6: LMR51430; SOT-23-6
USB1: TYPE-C 16PIN 2MD(073); USB-C-SMD_TYPE-C-6PIN-2MD-073; LCSC Part C2765186
X1: X322525MOB4SI; CRYSTAL-SMD_4P-L3.2-W2.5-BL; LCSC Part C9006
X2: Q13FC1350000400; FC-135R_L3.2-W1.5; LCSC Part C32346

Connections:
+3.3V: C17.1, C18.1, C19.1, C20.1, C21.1, C22.1, C23.1, C24.1, C25.1, C26.1, C27.1, C28.1, C29.1, C30.1, C31.1, Card1.4 (VDD), L4.2, L7.2, R7.2, R8.2, R9.2, R10.2, R11.2, R16.2, R17.2, R18.2, R19.2, R20.2, R21.2, SW2.1, U1.1 (VBAT), U1.19 (VDD), U1.32 (VDD), U1.48 (VDD), U1.64 (VDD), U3.5 (VDDIO), U3.8 (VDD), U4.1 (VDDIO), U4.10 (VDD); also elsewhere on the board
+5V: C10.1, C11.1, C12.1, C13.1, C38.2, C39.2, C40.2, D2.4 (VDD), J8.1, R13.1, S1.1, S2.1, S3.1, S4.1, U5.5 (FB), U5.7 (Vout), U5.8 (Vout); also elsewhere on the board
/BMP_INT: U1.62 (PB9), U4.7 (INT)
/BOOT: R22.2, SW2.2, U1.60 (BOOT0); also elsewhere on the board
/BQ_CE: U1.61 (PB8), U2.3 (~CE)
/BQ_INT: R11.1, U1.57 (PB5), U2.6 (~INT)
/BQ_PG: R8.1, U2.9 (~PG)
/BTST: C4.1, L5.1, U2.17 (SW), U2.18 (SW)
/HSE_IN: C33.1, U1.5 (PH0), X1.1 (OSC1)
/HSE_OUT: C34.1, U1.6 (PH1), X1.3 (OSC2)
/I2C_SCL: R10.1, U1.58 (PB6), U2.5 (SCL), U4.2 (SCK)
/I2C_SDA: R9.1, U1.59 (PB7), U2.4 (SDA), U4.4 (SDI)
/ICM_CS: U1.20 (PA4), U3.12 (AP_CS)
/ICM_INT1: U1.24 (PC4), U3.4 (INT1/INT)
/ICM_INT2: U1.25 (PB0), U3.9 (INT2/FSYNC/CLKIN)
/ICM_SCK: U1.21 (PA5), U3.13 (AP_SCL/AP_SCLK)
/ICM_SDI: U1.23 (PA7), U3.14 (AP_SDA/AP_SDIO/AP_SDI)
/ICM_SDO: U1.22 (PA6), U3.1 (AP_SDO/AP_AD0)
/LSE_IN: C35.1, U1.3 (PC14), X2.1
/LSE_OUT: C36.1, U1.4 (PC15), X2.2
/PPS: J8.4, U1.41 (PA8)
/PYRO_1: R25.1, U1.33 (PB12)
/PYRO_2: R27.1, U1.34 (PB13)
/PYRO_CON_1: R24.2, R26.1, U1.8 (PC0)
/PYRO_CON_2: R29.2, R30.1, U1.9 (PC1)
/RESET: C37.2, SW1.2, U1.7 (NRST); also elsewhere on the board
/SD_CD: Card1.9 (CD), U1.55 (PB3)
/SD_CLK: Card1.5 (CLK(SCLK)), R21.1, U1.53 (PC12)
/SD_CMD: Card1.3 (CMD(DI)), R20.1, U1.54 (PD2)
/SD_DAT0: Card1.7 (DAT0(D0)), R16.1, U1.39 (PC8)
/SD_DAT1: Card1.8 (DAT1(RSV)), R17.1, U1.40 (PC9)
/SD_DAT2: Card1.1 (DAT2(RSV)), R18.1, U1.51 (PC10)
/SD_DAT3: Card1.2 (CDDAT3(CS)), R19.1, U1.52 (PC11)
/SERVO1: S1.2, U1.14 (PA0); also elsewhere on the board
/SERVO2: S2.2, U1.15 (PA1); also elsewhere on the board
/SERVO3: S3.2, U1.16 (PA2); also elsewhere on the board
/SERVO4: S4.2, U1.17 (PA3); also elsewhere on the board
/STATUS_LED: R31.1, U1.2 (PC13)
/USART6_RX: J8.2, U1.38 (PC7); also elsewhere on the board
/USART6_TX: J8.3, U1.37 (PC6); also elsewhere on the board
/USB_DN: U1.44 (PA11), USB1.5 (DN2), USB1.7 (DN1)
/USB_DP: U1.45 (PA12), USB1.6 (DP1), USB1.8 (DP2)
BAT+: C2.1, J1.1, J6.1, J7.1, U2.13 (BAT), U2.14 (BAT); also elsewhere on the board
GND: C1.2, C2.2, C3.2, C5.2, C6.2, C7.2, C8.2, C9.2, C10.2, C11.2, C12.2, C13.2, C14.2, C16.2, C17.2, C18.2, C19.2, C20.2, C21.2, C22.2, C23.2, C24.2, C25.2, C26.2, C27.2, C28.2, C29.2, C30.2, C31.2, C32.2, C33.2, C34.2, C35.2, C36.2, C37.1, C38.1, C39.1, C40.1, Card1.6 (VSS), Card1.10 (GND), Card1.11 (GND), Card1.12 (GND), Card1.13 (GND), D2.2 (VSS), J1.2, J8.5, J8.S1 (SHIELD), J8.S2 (SHIELD), Q1.2 (S), Q2.2 (S), R1.2, R2.2, R3.2, R5.1, R6.1, R15.1, R22.1, R23.2, R26.2, R28.2, R30.2, S1.3, S2.3, S3.3, S4.3, SW1.1, U1.12 (VSSA), U1.18 (VSS), U1.31 (VSS), U1.47 (VSS), U1.63 (VSS), U2.19 (GND), U2.20 (GND), U2.25 (EP), U3.6 (GND), U4.3 (VSS), U4.5 (SDO), U4.6 (CSB), U4.8 (VSS), U4.9 (VSS), U5.4 (GND), U5.6 (FB2), U5.10 (PGND), U5.15 (Vsel), U6.1 (GND), USB1.1 (GND), USB1.12 (GND), USB1.13 (SHELL), USB1.14 (SHELL), X1.2 (GND), X1.4 (GND); also elsewhere on the board
unnamed: C5.1, L5.2, U2.21 (PMID), U2.22 (PMID)
unnamed: D1.2 (A), U2.2 (STAT)
unnamed: D1.1 (K), R7.1
unnamed: D2.3 (DIN), R31.2
unnamed: J6.2, Q1.3 (D), R24.1
unnamed: J7.2, Q2.3 (D), R29.1
unnamed: Q1.1 (G), R23.1, R25.2
unnamed: Q2.1 (G), R27.2, R28.1
unnamed: C32.1, U1.30 (VCAP_1)
unnamed: L4.1, U1.13 (VDDA)
unnamed: C4.2, U2.12 (BTST)
unnamed: R3.1, U2.8 (ILIM)
unnamed: R4.1, R5.2, R6.2, U2.7 (TS)
unnamed: R12.1, U5.1 (PS/SYNC), U5.14 (EN)
unnamed: L6.2, U5.11 (L1)
unnamed: L6.1, U5.9 (L2)
unnamed: R13.2, U5.2 (PG)
unnamed: C14.1, U5.3 (Vaux)
unnamed: C15.1, U6.6 (CB)
unnamed: R14.1, R15.2, U6.4 (FB)
unnamed: C15.2, L7.1, R14.2, U6.2 (SW)
unnamed: R1.1, USB1.4 (CC1)
unnamed: R2.1, USB1.10 (CC2)
VBUS: C1.1, U2.23 (VBUS), USB1.2 (VBUS), USB1.11 (VBUS)
VREGN: C3.1, R4.2, U2.11 (REGN)
VSYS: C6.1, C7.1, C8.1, C9.1, C16.1, R12.2, U2.15 (SYS), U2.16 (SYS), U5.12 (Vin), U5.13 (Vin), U6.3 (VIN), U6.5 (EN)

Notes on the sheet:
STM32
Button
Buck stepup 5v
Crytsals
Presure Sensor
GPS
USB C
MICRO SD
IMU
Battery Charger
Buck 3.3v
Pyros
Status LED
Servo
Decopling caps

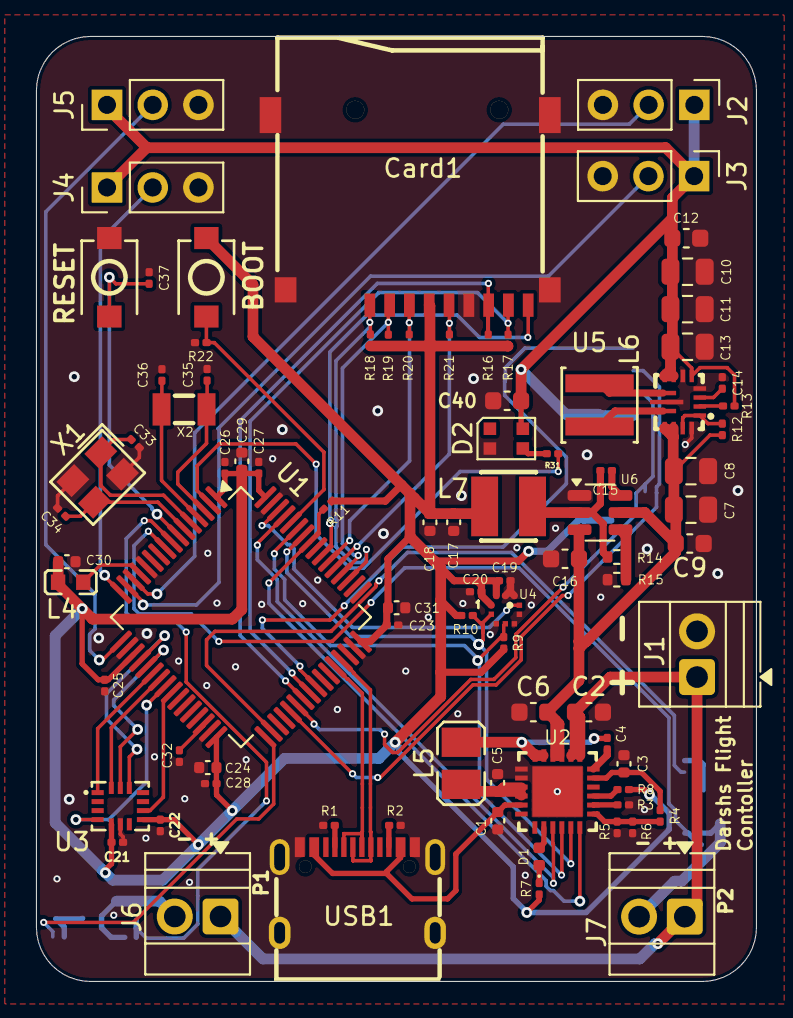
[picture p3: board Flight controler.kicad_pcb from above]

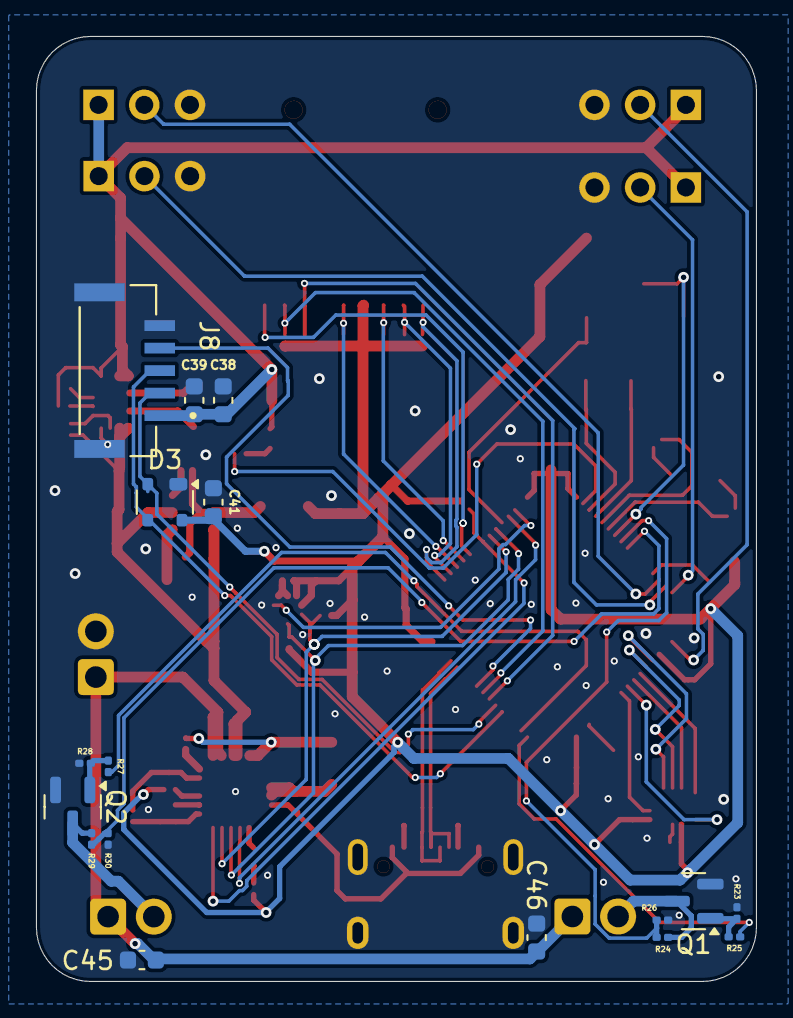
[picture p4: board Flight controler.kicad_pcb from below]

Board: 2 copper layers, 40.0 x 52.5 mm, 103 parts (17 on the bottom side), 70 nets.

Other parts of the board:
BOOT: TS-1088-AR02016; SW-SMD_L3.9-W3.0-P4.45
C41, C45, C46: 100nf; C_0603_1608Metric
D3: PRTR5V0U2X; SOT-143
J2, J3, J4, J5: Conn_01x03; PinHeader_1x03_P2.54mm_Vertical
RESET: TS-1088-AR02016; SW-SMD_L3.9-W3.0-P4.45

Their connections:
+3.3V: BOOT.1, C41.1, D3.4 (VCC); also elsewhere on the board
+5V: J2.1, J3.1, J4.1, J5.1; also elsewhere on the board
/BOOT: BOOT.2; also elsewhere on the board
/RESET: RESET.2; also elsewhere on the board
/SERVO1: J2.2; also elsewhere on the board
/SERVO2: J3.2; also elsewhere on the board
/SERVO3: J4.2; also elsewhere on the board
/SERVO4: J5.2; also elsewhere on the board
/USART6_RX: D3.2 (I/O1); also elsewhere on the board
/USART6_TX: D3.3 (I/O2); also elsewhere on the board
BAT+: C45.2, C46.2; also elsewhere on the board
GND: C41.2, C45.1, C46.1, D3.1 (GND), J2.3, J3.3, J4.3, J5.3, RESET.1; also elsewhere on the board

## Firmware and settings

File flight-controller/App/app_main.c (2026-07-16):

/* ============================================================
 * app_main.c: module bring-up + bare-metal superloop (CLAUDE.md §5.7).
 * Rates: control/log 200 Hz, LED 5 Hz, charger 1 Hz; GPS/console/
 * telemetry/pyro/SD polled every pass (all non-blocking).
 * ============================================================ */
#include "app.h"
#include <stdio.h>
#include <string.h>

#define CTRL_DT_MS (1000u / CTRL_HZ)

static uint32_t s_next_ctrl;
static uint32_t s_next_led;
static uint32_t s_next_chg;
static uint32_t s_next_sd;
static bool     s_sd_present;        /* card-detect edge tracking */

static IWDG_HandleTypeDef s_iwdg;

/* Read RCC->CSR reset flags into a short string, then clear them so the
 * next reset reports fresh causes. Call before anything else can reset. */
static void reset_cause_read(char *buf, size_t n)
{
    buf[0] = '\0';
    if (__HAL_RCC_GET_FLAG(RCC_FLAG_LPWRRST)) strncat(buf, " LPWR", n - strlen(buf) - 1u);
    if (__HAL_RCC_GET_FLAG(RCC_FLAG_WWDGRST)) strncat(buf, " WWDG", n - strlen(buf) - 1u);
    if (__HAL_RCC_GET_FLAG(RCC_FLAG_IWDGRST)) strncat(buf, " IWDG", n - strlen(buf) - 1u);
    if (__HAL_RCC_GET_FLAG(RCC_FLAG_SFTRST))  strncat(buf, " SFT",  n - strlen(buf) - 1u);
    if (__HAL_RCC_GET_FLAG(RCC_FLAG_PORRST))  strncat(buf, " POR",  n - strlen(buf) - 1u);
    if (__HAL_RCC_GET_FLAG(RCC_FLAG_BORRST))  strncat(buf, " BOR",  n - strlen(buf) - 1u);
    if (__HAL_RCC_GET_FLAG(RCC_FLAG_PINRST))  strncat(buf, " PIN",  n - strlen(buf) - 1u);
    if (buf[0] == '\0')
        strncat(buf, " none", n - strlen(buf) - 1u);
    __HAL_RCC_CLEAR_RESET_FLAGS();
}

void app_init(void)
{
    char rst[40];
    reset_cause_read(rst, sizeof rst);   /* first: flags survive only until cleared */

    /* Console first so every later init can report over USB. */
    console_init();
    usb_device_init();
    led_init();
    led_set(8, 8, 8);                    /* dim white: booting */

    servo_init();
    /* Park the main-release servo at SAFE (retained) immediately: servo_init
     * centers all channels (1500 us), which for the release mechanism could be
     * a partial release. Holds SAFE across the whole boot window until fsm_step
     * takes over (state_machine.c drives it every control pass). */
    servo_set_us(SERVO_DEPLOY_IDX, SERVO_SAFE_US);
    int rc_pyro  = pyro_init();
    int rc_imu   = imu_init();
    int rc_baro  = baro_init();
    int rc_chg   = charger_init();
    int rc_radio = radio_init();
    int rc_gps   = gps_init();
    int rc_sd    = datalog_init();
    telem_init();
    fsm_init();                          /* zeroes g_fsm; flags set below */

    /* Persisted params (flash sector 7): override the compile-time defaults
     * if a valid record exists. See param_store.c for what must never be
     * persisted. Last GPS (from the previous landing) is logged for recovery. */
    {
        params_t pp;
        if (param_load(&pp) == 0) {
            fsm_params_apply(&pp);
            char msg[72];
            snprintf(msg, sizeof msg, "PARAM main_alt=%lu cm apogee_to=%lu ms",
                     (unsigned long)pp.main_alt_cm,
                     (unsigned long)pp.apogee_timeout_ms);
            datalog_event(msg);
            if (pp.last_lat_e7 != 0 || pp.last_lon_e7 != 0) {
                snprintf(msg, sizeof msg, "LAST GPS lat=%ld lon=%ld e7 (recovery)",
                         (long)pp.last_lat_e7, (long)pp.last_lon_e7);
                datalog_event(msg);
            }
        }
    }

    g_fsm.imu_ok   = (rc_imu == 0);
    g_fsm.baro_ok  = (rc_baro == 0);
    g_fsm.sd_ok    = (rc_sd == 0) && datalog_ok();
    g_fsm.radio_ok = (rc_radio == 0) && radio_ok();
    g_fsm.chg_ok   = (rc_chg == 0);
    g_fsm.gps_ok   = (rc_gps == 0);

    /* IWDG after every slow init above: LSI 32 kHz nominal (up to ~47 kHz
     * spec) / 32 with full reload = ~4.1 s nominal, ~2.8 s worst case.
     * Refreshed once per app_loop() pass AND at the SD liveness point in
     * sd_diskio.c (a healthy-but-slow card can legally hold one FatFs call
     * for seconds, and that is progress, not a hang). */
    s_iwdg.Instance       = IWDG;
    s_iwdg.Init.Prescaler = IWDG_PRESCALER_32;
    s_iwdg.Init.Reload    = 4095u;
    s_iwdg.Init.Window    = IWDG_WINDOW_DISABLE;
    int rc_wdg = (HAL_IWDG_Init(&s_iwdg) == HAL_OK) ? 0 : -1;

    console_printf("\r\n=== FC boot ===\r\n");
    console_printf("reset:%s\r\n", rst);
    console_printf("imu:%s baro:%s chg:%s radio:%s(%s) gps:%s sd:%s pyro:%s wdg:%s\r\n",
                   rc_imu   == 0 ? "ok" : "FAIL",
                   rc_baro  == 0 ? "ok" : "FAIL",
                   rc_chg   == 0 ? "ok" : "FAIL",
                   rc_radio == 0 ? "ok" : "FAIL",
                   radio_using_tcxo() ? "tcxo" : "xtal",
                   rc_gps   == 0 ? "ok" : "FAIL",
                   g_fsm.sd_ok ? "ok" : "none",
                   rc_pyro  == 0 ? "ok" : "FAIL",
                   rc_wdg   == 0 ? "ok" : "FAIL");
    datalog_event("BOOT");
    {
        char msg[24];
        snprintf(msg, sizeof msg, "RST:%s", rst);
        datalog_event(msg);
    }
    if (rc_wdg != 0)
        datalog_event("WDG INIT FAIL");

    uint32_t now = HAL_GetTick();
    s_next_ctrl = now + CTRL_DT_MS;
    s_next_led  = now + (1000u / LED_HZ);
    s_next_chg  = now + 1000u;
    s_next_sd   = now + SD_RETRY_PERIOD_MS;
    s_sd_present = datalog_card_present();  /* boot attempt covered this
                                               insertion, no blind retry */
}

static void push_log_record(uint32_t now_ms)
{
    log_record_t r;
    memset(&r, 0, sizeof r);
    r.magic      = LOG_RECORD_MAGIC;
    r.state      = (uint8_t)g_fsm.state;
    r.flags      = (uint16_t)((g_fsm.gps.fix       ? FLAG_GPS_FIX   : 0) |
                              (g_fsm.imu.accel_sat ? FLAG_ACCEL_SAT : 0) |
                              (g_fsm.armed         ? FLAG_ARMED     : 0) |
                              (g_fsm.sd_ok         ? FLAG_SD_OK     : 0) |
                              (g_fsm.chg_ok        ? FLAG_CHG_OK    : 0) |
                              (g_fsm.gps_ok        ? FLAG_GPS_OK    : 0));
    r.t_ms       = now_ms;
    r.ax_g       = g_fsm.imu.ax;
    r.ay_g       = g_fsm.imu.ay;
    r.az_g       = g_fsm.imu.az;
    r.gx_dps     = g_fsm.imu.gx;
    r.gy_dps     = g_fsm.imu.gy;
    r.gz_dps     = g_fsm.imu.gz;
    r.press_pa   = g_fsm.press_pa;
    r.temp_c     = g_fsm.temp_c;
    r.agl_m      = g_fsm.agl_m;
    r.vel_ms     = g_fsm.vel_ms;
    r.lat_e7     = g_fsm.gps.lat_e7;
    r.lon_e7     = g_fsm.gps.lon_e7;
    r.alt_gps_cm = g_fsm.gps.alt_msl_cm;
    r.sats       = g_fsm.gps.sats;
    r.pyro_cont  = pyro_cont_bits();
    r.pyro_fired = pyro_fired_bits();
    r.batt_mv    = g_fsm.chg.vbat_mv;
    datalog_push(&r);                    /* datalog computes the CRC */
}

void app_loop(void)
{
    uint32_t now = HAL_GetTick();

    HAL_IWDG_Refresh(&s_iwdg);           /* worst single pass << 4.1 s timeout */

    /* 200 Hz control + logging tick (drift-free; resync if badly late) */
    if ((int32_t)(now - s_next_ctrl) >= 0) {
        if ((int32_t)(now - s_next_ctrl) > 100)
            s_next_ctrl = now;           /* SD hiccup etc: resync, don't burst */
        s_next_ctrl += CTRL_DT_MS;
        fsm_step(now);
        push_log_record(now);
    }

    /* every pass, all non-blocking */
    gps_poll();
    pyro_poll();
    telem_poll(now);
    datalog_poll(now);
    console_poll();

    if ((int32_t)(now - s_next_led) >= 0) {
        s_next_led = now + (1000u / LED_HZ);
        g_fsm.sd_ok = datalog_ok();
        led_poll(g_fsm.state, g_fsm.armed, g_fsm.sd_ok, g_fsm.gps.fix);
        if (g_fsm.state == ST_GROUND_IDLE && !g_fsm.armed)
            baro_ground_track();         /* absorb weather/thermal drift */
    }

    if ((int32_t)(now - s_next_chg) >= 0) {
        s_next_chg = now + 1000u;
        charger_poll(&g_fsm.chg);
    }

    /* SD auto-retry: EDGE-TRIGGERED, one attempt per physical card
     * insertion (remove -> insert observed while running), never a blind
     * timer. A half-seated card can hang HAL_SD_Init past the IWDG
     * budget, and since RAM counters reset with each watchdog reboot, a
     * periodic retry turns one bad card into an infinite ~9 s reboot
     * loop (observed on the bench, 2026-07-10). Boot still attempts once;
     * a card that misses boot heals via reseat or console/deck `log
     * start`. GROUND STATES ONLY. */
    if ((int32_t)(now - s_next_sd) >= 0) {
        s_next_sd = now + SD_RETRY_PERIOD_MS;
        bool present = datalog_card_present();
        if (present && !s_sd_present && !g_fsm.sd_ok &&
            (g_fsm.state == ST_INIT || g_fsm.state == ST_GROUND_IDLE ||
             g_fsm.state == ST_LANDED)) {
            wdg_refresh();               /* deliberate ground-state work */
            if (datalog_init() == 0) {
                g_fsm.sd_ok = datalog_ok();
                datalog_event("SD REINIT OK");
            }
            wdg_refresh();
        }
        s_sd_present = present;
    }
}

/* Kick the watchdog from a known-liveness point outside app_loop (the SD
 * card-busy wait in sd_diskio.c). Safe before init: Instance still NULL. */
void wdg_refresh(void)
{
    if (s_iwdg.Instance != NULL)
        (void)HAL_IWDG_Refresh(&s_iwdg);
}

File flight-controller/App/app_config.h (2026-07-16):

#pragma once
/* ============================================================
 * app_config.h: tunable constants (thresholds per CLAUDE.md §5.4)
 * All flight thresholds must be re-tuned to the motor/airframe.
 * ============================================================ */

/* ---- Scheduling (superloop, HAL tick = 1 kHz) ---- */
#define CTRL_HZ              200     /* sensor sample + state machine */
#define BARO_HZ              50      /* BMP580 continuous-mode readout */
#define CONT_HZ              10      /* pyro continuity ADC poll */
#define CHARGER_HZ           1       /* BQ25883 poll */
#define LED_HZ               5
#define LOG_FLUSH_MS         500     /* f_sync cadence */

/* ---- Telemetry cadence (per CLAUDE.md §4) ---- */
#define TELEM_PERIOD_PAD_MS     1000
#define TELEM_PERIOD_FLIGHT_MS  100
#define TELEM_PERIOD_LANDED_MS  500   /* raised rate for recovery */
#define PAD_RX_WINDOW_MS        300   /* RX window after each pad TX; TX-only in flight */
#define TELEM_TX_TIMEOUT_MS     2000  /* force-clear a stuck TX (airtime ~40 ms) */
#define RADIO_REINIT_PERIOD_MS  5000  /* retry radio_init while dead, ground states only */
#define SD_RETRY_PERIOD_MS      5000  /* retry datalog_init while dead, ground states only */

/* ---- Flight detection thresholds ---- */
#define LAUNCH_G             3.0f    /* |accel| sustained above this ... */
#define LAUNCH_DEBOUNCE_MS   150     /* ... for this long => BOOST */
#define LAUNCH_BARO_ALT_M    10.0f   /* OR baro AGL rising above this (accel may be saturated) */
#define BURNOUT_G            0.5f    /* axial accel below this ... */
#define BURNOUT_DEBOUNCE_MS  200     /* ... for this long => COAST */
#define MAX_BURN_MS          6000    /* backup: force COAST */
#define APOGEE_DEBOUNCE_N    10      /* consecutive 200 Hz samples with vel<=0 + alt falling */
#define APOGEE_TIMEOUT_MS    30000   /* DEFAULT apogee backup timer from launch; runtime
                                      * value g_fsm.apogee_timeout_ms (settable + persisted)
                                      * drives both the ST_COAST force-apogee and the
                                      * fault-independent backup deploy. TUNE per motor. */
#define MAIN_ALT_M_DEFAULT   150.0f  /* main-deploy AGL (runtime-settable, CMD_SET_MAIN_ALT) */
#define LAND_VEL_MS          1.0f    /* |vertical vel| below this ... */
#define LAND_DEBOUNCE_MS     10000   /* ... with stable alt for this long => LANDED */
#define MIN_DROGUE_DELAY_MS  3000    /* never fire drogue sooner than this after launch */
/* Fault-independent backup deploy fires at g_fsm.apogee_timeout_ms after launch
 * EVEN in ST_FAULT / with dead sensors (bypasses the armed gate); it is the last
 * line against a lawn-dart. Shares the (tunable) apogee timeout; too early = deploy
 * during ascent, so TUNE apogee_timeout to just past expected apogee. */

/* ---- Pyro (per CLAUDE.md §2, safety-critical) ---- */
#define FIRE_PULSE_MS        1000
#define FIRE_RETRY_MAX       1       /* single retry if continuity persists */
#define CONT_THRESH_MV       300     /* >this at PC1 (pin mV) = continuity */
#define TEST_FIRE_PASSCODE   0x52A5u /* upper 16 bits of CMD_TEST_FIRE arg; low 16 = channel */

/* ---- Servo main-release (no 2nd pyro on this board; a servo mechanically
 *      releases the main chute at the DROGUE->MAIN deploy point) ----
 * ⚠ MOUNT KNOBS, mechanism-specific; measure the actual release geometry.
 * Both endpoints must sit in the 500..2500 us servo range. */
#define SERVO_DEPLOY_IDX     0       /* which TIM2 servo actuates the release */
#define SERVO_SAFE_US        1000    /* main retained / held in: SAFE */
#define SERVO_RELEASE_US     2000    /* main released */

/* ---- Sensors ---- */
#define ACCEL_FS_G           16      /* ISM330DHCX max; saturation => boolean-only in boost */
#define ACCEL_SAT_G          15.5f   /* any axis beyond this => FLAG_ACCEL_SAT */
#define GYRO_FS_DPS          2000
#define GYRO_CAL_SAMPLES     400     /* pad gyro bias cal (~2 s at 200 Hz), stationary */
#define GYRO_CAL_MAX_PP_DPS  5.0f    /* per-axis peak-to-peak ceiling during cal; over => restart */
#define GYRO_CAL_ACC_BAND_G  0.15f   /* |a|-1g must stay inside this during cal; over => restart */
#define IMU_FREEZE_N         10      /* N byte-identical 12-B bursts (BDU on) => stuck bus */
#define SEA_LEVEL_PA_DEFAULT 101325.0f
#define BARO_TRACK_ALPHA     0.003f  /* pad AGL-zero drift tracking at LED_HZ:
                                        tau ~= 1/(alpha*5 Hz) ~= 67 s; frozen
                                        outside GROUND_IDLE-disarmed */

/* ---- Kalman (1-D altitude/velocity, baro-driven) ---- */
#define KAL_Q_ACCEL          4.0f    /* process noise (m/s^2)^2 */
#define KAL_R_BARO           1.5f    /* baro meas noise m^2 */
#define KAL_GATE_SIGMA       5.0f    /* innovation gate: reject y^2 > N^2*S */
#define KAL_GATE_MAX_REJECT  25      /* ~0.5 s at 50 Hz, then accept (real step) */
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

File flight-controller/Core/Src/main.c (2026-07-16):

/* ============================================================
 * main.c: Flight Controller (STM32F722RET6)
 * Boot order is safety-critical (CLAUDE.md §2): the pyro gate is
 * forced LOW as the very first action after reset, before HAL,
 * clocks, or any other init.
 * ============================================================ */
#include "main.h"
#include "app.h"

SPI_HandleTypeDef  hspi1;
I2C_HandleTypeDef  hi2c1;
SD_HandleTypeDef   hsd1;
TIM_HandleTypeDef  htim2;
UART_HandleTypeDef huart6;
ADC_HandleTypeDef  hadc1;
/* hpcd_USB_OTG_FS lives in App/usb/usbd_conf.c */

void SystemClock_Config(void);
static void MPU_Config(void);
static void MX_GPIO_Init(void);
static void MX_I2C1_Init(void);
static void MX_SPI1_Init(void);
static void MX_SDMMC1_SD_Init(void);
static void MX_TIM2_Init(void);
static void MX_USART6_UART_Init(void);
static void MX_ADC1_Init(void);

int main(void)
{
  /* SAFETY: pyro gate LOW, push-pull, before anything else. */
  pyro_boot_safe();

  MPU_Config();
  SCB_EnableICache();
  HAL_Init();
  SystemClock_Config();

  MX_GPIO_Init();
  MX_SPI1_Init();
  MX_I2C1_Init();
  MX_TIM2_Init();
  MX_USART6_UART_Init();
  MX_ADC1_Init();
  MX_SDMMC1_SD_Init();   /* may fail with no card; app handles */

  app_init();
  while (1)
  {
    app_loop();
  }
}

/* 216 MHz SYSCLK from 25 MHz HSE; 48 MHz PLLQ for USB + SDMMC.
 * APB1 = 54 MHz (max), APB2 = 108 MHz. Overdrive required at 216 MHz. */
void SystemClock_Config(void)
{
  RCC_OscInitTypeDef RCC_OscInitStruct = {0};
  RCC_ClkInitTypeDef RCC_ClkInitStruct = {0};
  RCC_PeriphCLKInitTypeDef PeriphClkInitStruct = {0};

  __HAL_RCC_PWR_CLK_ENABLE();
  __HAL_PWR_VOLTAGESCALING_CONFIG(PWR_REGULATOR_VOLTAGE_SCALE1);

  RCC_OscInitStruct.OscillatorType = RCC_OSCILLATORTYPE_HSE;
  RCC_OscInitStruct.HSEState = RCC_HSE_ON;
  RCC_OscInitStruct.PLL.PLLState = RCC_PLL_ON;
  RCC_OscInitStruct.PLL.PLLSource = RCC_PLLSOURCE_HSE;
  RCC_OscInitStruct.PLL.PLLM = 25;            /* 25 MHz / 25 = 1 MHz VCO in */
  RCC_OscInitStruct.PLL.PLLN = 432;           /* 432 MHz VCO out */
  RCC_OscInitStruct.PLL.PLLP = RCC_PLLP_DIV2; /* 216 MHz SYSCLK */
  RCC_OscInitStruct.PLL.PLLQ = 9;             /* 48 MHz USB/SDMMC */
  if (HAL_RCC_OscConfig(&RCC_OscInitStruct) != HAL_OK)
    Error_Handler();

  if (HAL_PWREx_EnableOverDrive() != HAL_OK)
    Error_Handler();

  RCC_ClkInitStruct.ClockType = RCC_CLOCKTYPE_HCLK|RCC_CLOCKTYPE_SYSCLK
                              |RCC_CLOCKTYPE_PCLK1|RCC_CLOCKTYPE_PCLK2;
  RCC_ClkInitStruct.SYSCLKSource = RCC_SYSCLKSOURCE_PLLCLK;
  RCC_ClkInitStruct.AHBCLKDivider = RCC_SYSCLK_DIV1;
  RCC_ClkInitStruct.APB1CLKDivider = RCC_HCLK_DIV4;
  RCC_ClkInitStruct.APB2CLKDivider = RCC_HCLK_DIV2;
  if (HAL_RCC_ClockConfig(&RCC_ClkInitStruct, FLASH_LATENCY_7) != HAL_OK)
    Error_Handler();

  PeriphClkInitStruct.PeriphClockSelection = RCC_PERIPHCLK_CLK48|RCC_PERIPHCLK_SDMMC1;
  PeriphClkInitStruct.Clk48ClockSelection = RCC_CLK48SOURCE_PLL;
  PeriphClkInitStruct.Sdmmc1ClockSelection = RCC_SDMMC1CLKSOURCE_CLK48;
  if (HAL_RCCEx_PeriphCLKConfig(&PeriphClkInitStruct) != HAL_OK)
    Error_Handler();
}

static void MX_SPI1_Init(void)
{
  /* Shared bus: ISM330DHCX + SX1262, both SPI mode 0, GPIO CS.
   * APB2 108 MHz / 16 = 6.75 MHz. */
  hspi1.Instance = SPI1;
  hspi1.Init.Mode = SPI_MODE_MASTER;
  hspi1.Init.Direction = SPI_DIRECTION_2LINES;
  hspi1.Init.DataSize = SPI_DATASIZE_8BIT;
  hspi1.Init.CLKPolarity = SPI_POLARITY_LOW;
  hspi1.Init.CLKPhase = SPI_PHASE_1EDGE;
  hspi1.Init.NSS = SPI_NSS_SOFT;
  hspi1.Init.BaudRatePrescaler = SPI_BAUDRATEPRESCALER_16;
  hspi1.Init.FirstBit = SPI_FIRSTBIT_MSB;
  hspi1.Init.TIMode = SPI_TIMODE_DISABLE;
  hspi1.Init.CRCCalculation = SPI_CRCCALCULATION_DISABLE;
  hspi1.Init.CRCPolynomial = 7;
  hspi1.Init.NSSPMode = SPI_NSS_PULSE_DISABLE;
  if (HAL_SPI_Init(&hspi1) != HAL_OK)
    Error_Handler();
}

static void MX_I2C1_Init(void)
{
  /* Kernel clock = PCLK1 54 MHz. PRESC=13 -> 3.857 MHz tick;
   * SCLL=19/SCLH=17 -> ~97 kHz. Conservative for BMP580 + BQ25883. */
  hi2c1.Instance = I2C1;
  hi2c1.Init.Timing = 0xD0421113;
  hi2c1.Init.OwnAddress1 = 0;
  hi2c1.Init.AddressingMode = I2C_ADDRESSINGMODE_7BIT;
  hi2c1.Init.DualAddressMode = I2C_DUALADDRESS_DISABLE;
  hi2c1.Init.OwnAddress2 = 0;
  hi2c1.Init.OwnAddress2Masks = I2C_OA2_NOMASK;
  hi2c1.Init.GeneralCallMode = I2C_GENERALCALL_DISABLE;
  hi2c1.Init.NoStretchMode = I2C_NOSTRETCH_DISABLE;
  if (HAL_I2C_Init(&hi2c1) != HAL_OK)
    Error_Handler();
  if (HAL_I2CEx_ConfigAnalogFilter(&hi2c1, I2C_ANALOGFILTER_ENABLE) != HAL_OK)
    Error_Handler();
  if (HAL_I2CEx_ConfigDigitalFilter(&hi2c1, 0) != HAL_OK)
    Error_Handler();
}

static void MX_SDMMC1_SD_Init(void)
{
  /* HAL_SD_Init is called lazily by datalog_init() so a missing card
   * doesn't hang boot; here we only fill the handle. 48 MHz kernel;
   * ClockDiv 0 -> 24 MHz after init phase. */
  hsd1.Instance = SDMMC1;
  hsd1.Init.ClockEdge = SDMMC_CLOCK_EDGE_RISING;
  hsd1.Init.ClockBypass = SDMMC_CLOCK_BYPASS_DISABLE;
  hsd1.Init.ClockPowerSave = SDMMC_CLOCK_POWER_SAVE_DISABLE;
  hsd1.Init.BusWide = SDMMC_BUS_WIDE_1B;
  hsd1.Init.HardwareFlowControl = SDMMC_HARDWARE_FLOW_CONTROL_DISABLE;
  hsd1.Init.ClockDiv = 0;
}

static void MX_TIM2_Init(void)
{
  /* 4x servo PWM, 50 Hz. Timer clock = 108 MHz; PSC->1 MHz; ARR 20000. */
  TIM_MasterConfigTypeDef sMasterConfig = {0};
  TIM_OC_InitTypeDef sConfigOC = {0};

  htim2.Instance = TIM2;
  htim2.Init.Prescaler = 108 - 1;
  htim2.Init.CounterMode = TIM_COUNTERMODE_UP;
  htim2.Init.Period = 20000 - 1;
  htim2.Init.ClockDivision = TIM_CLOCKDIVISION_DIV1;
  htim2.Init.AutoReloadPreload = TIM_AUTORELOAD_PRELOAD_ENABLE;
  if (HAL_TIM_PWM_Init(&htim2) != HAL_OK)
    Error_Handler();
  sMasterConfig.MasterOutputTrigger = TIM_TRGO_RESET;
  sMasterConfig.MasterSlaveMode = TIM_MASTERSLAVEMODE_DISABLE;
  if (HAL_TIMEx_MasterConfigSynchronization(&htim2, &sMasterConfig) != HAL_OK)
    Error_Handler();
  sConfigOC.OCMode = TIM_OCMODE_PWM1;
  sConfigOC.Pulse = 1500;                  /* center */
  sConfigOC.OCPolarity = TIM_OCPOLARITY_HIGH;
  sConfigOC.OCFastMode = TIM_OCFAST_DISABLE;
  if (HAL_TIM_PWM_ConfigChannel(&htim2, &sConfigOC, TIM_CHANNEL_1) != HAL_OK ||
      HAL_TIM_PWM_ConfigChannel(&htim2, &sConfigOC, TIM_CHANNEL_2) != HAL_OK ||
      HAL_TIM_PWM_ConfigChannel(&htim2, &sConfigOC, TIM_CHANNEL_3) != HAL_OK ||
      HAL_TIM_PWM_ConfigChannel(&htim2, &sConfigOC, TIM_CHANNEL_4) != HAL_OK)
    Error_Handler();
  HAL_TIM_MspPostInit(&htim2);
}

static void MX_USART6_UART_Init(void)
{
  huart6.Instance = USART6;
  huart6.Init.BaudRate = 9600;             /* gps.c re-inits during autobaud */
  huart6.Init.WordLength = UART_WORDLENGTH_8B;
  huart6.Init.StopBits = UART_STOPBITS_1;
  huart6.Init.Parity = UART_PARITY_NONE;
  huart6.Init.Mode = UART_MODE_TX_RX;
  huart6.Init.HwFlowCtl = UART_HWCONTROL_NONE;
  huart6.Init.OverSampling = UART_OVERSAMPLING_16;
  if (HAL_UART_Init(&huart6) != HAL_OK)
    Error_Handler();
}
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

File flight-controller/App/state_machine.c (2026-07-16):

/* ============================================================
 * state_machine.c: flight state machine + sensor-fusion glue.
 * SAFETY-CRITICAL (CLAUDE.md §2, §5.4). Every pyro decision is made
 * here and only here; radio commands can never fire in flight.
 *
 * Runs at CTRL_HZ (200 Hz) from app_loop. Superloop context only:
 * nothing here is touched from an ISR, so g_fsm needs no volatile.
 * ============================================================ */
#include "app.h"
#include <math.h>
#include <string.h>

fsm_t g_fsm;

/* ---- derived scheduling constants ---- */
#define CTRL_DT_MS        (1000u / CTRL_HZ)              /* 5 ms          */
#define CTRL_DT_S         (1.0f / (float)CTRL_HZ)
#define BARO_DECIM        (CTRL_HZ / BARO_HZ)            /* every 4 steps */
#define GPS_DECIM         (CTRL_HZ / 5)                  /* gps copy 5 Hz */
#define LAUNCH_ACC_N      (LAUNCH_DEBOUNCE_MS / CTRL_DT_MS)   /* 30 */
#define LAUNCH_BARO_N     4        /* consecutive rising-AGL samples       */
#define BURNOUT_N         (BURNOUT_DEBOUNCE_MS / CTRL_DT_MS)  /* 40 */
#define INIT_OK_N         20       /* 100 ms of healthy sensors -> IDLE    */
#define IMU_FAIL_N        (CTRL_HZ / 2)   /* 0.5 s of consecutive failures */
#define BARO_FAIL_N       (BARO_HZ / 2)   /* 0.5 s of consecutive failures */
#define APOGEE_PEAK_MARGIN_M  0.25f /* "below peak" noise guard            */
#define LAND_ALT_BAND_M       2.0f  /* alt considered stable within this   */

/* ---- private filter + debounce state ---- */
static kalman_t s_kal;
static uint32_t s_step;
static uint16_t s_imu_fail, s_baro_fail;
static uint16_t s_init_ok_cnt;
static uint16_t s_launch_acc_cnt, s_launch_baro_cnt;
static uint16_t s_burnout_cnt;
static uint16_t s_apogee_cnt;
static float    s_peak_agl;
static bool     s_land_win;         /* landing debounce window open */
static uint32_t s_land_start_ms;
static float    s_land_ref_agl;
static bool     s_deploy_fired;     /* a deploy (primary OR backup) has been commanded */
static bool     s_main_released;    /* servo main-release latched (never during ascent) */

const char *fsm_state_name(flight_state_t s)
{
    static const char *const names[] = {
        "INIT", "GROUND_IDLE", "ARMED", "BOOST", "COAST",
        "APOGEE", "DROGUE", "MAIN", "DESCENT", "LANDED", "FAULT"
    };
    if ((unsigned)s >= sizeof(names) / sizeof(names[0]))
        return "?";
    return names[s];
}

/* Transition + PKT_EVENT + log entry (telem_event also writes the
 * datalog sidecar with the state name). */
static void fsm_set_state(flight_state_t s)
{
    if (g_fsm.state == s)
        return;
    g_fsm.state = s;
    telem_event((uint8_t)s);
}

static void fsm_fault(const char *why)
{
    if (g_fsm.state == ST_FAULT)
        return;
    g_fsm.armed = false;            /* safe pyros: pyro_fire ignores !armed */
    datalog_event(why);
    datalog_flush();                /* bounded drain + sync, since FAULT may precede power loss */
    fsm_set_state(ST_FAULT);        /* logging + telemetry keep running */
}

void fsm_init(void)
{
    memset(&g_fsm, 0, sizeof g_fsm);
    g_fsm.state        = ST_INIT;
    g_fsm.main_alt_m   = MAIN_ALT_M_DEFAULT;
    g_fsm.apogee_timeout_ms = APOGEE_TIMEOUT_MS;  /* per-motor; param_load may override */
    g_fsm.test_enabled = false;     /* enabled only via console, never radio */
    kal_reset(&s_kal);
    s_step = 0;
    s_imu_fail = s_baro_fail = 0;
    s_init_ok_cnt = 0;
    s_launch_acc_cnt = s_launch_baro_cnt = 0;
    s_burnout_cnt = s_apogee_cnt = 0;
    s_peak_agl = 0.0f;
    s_land_win = false;
    s_deploy_fired = false;
    s_main_released = false;
}

int fsm_request_arm(bool via_radio)
{
    /* Full arming gate per CLAUDE.md §2: explicit command + sensors
     * healthy + on-pad sanity. ALL conditions required. */
    if (g_fsm.state != ST_GROUND_IDLE)          return -1;
    if (!g_fsm.imu_ok || !g_fsm.baro_ok)        return -2;
    if (!imu_gyro_cal_done())                   return -3;  /* pad cal must finish */
    if (fabsf(g_fsm.vel_ms) >= ARM_MAX_VEL_MS)  return -4;

    const float a[3] = { g_fsm.imu.ax, g_fsm.imu.ay, g_fsm.imu.az };
    float amag = sqrtf(a[0] * a[0] + a[1] * a[1] + a[2] * a[2]);
    if (g_fsm.imu.accel_sat)                    return -5;  /* impossible on pad */
    if (fabsf(amag - 1.0f) >= ARM_MAX_TILT_G)   return -5;  /* gross |a| sanity */

    /* Orientation gate (fixes the old magnitude-only band that let a rocket
     * on its side arm): the up-axis must read ~+1 g and lateral g must be
     * small. Auto-picks the dominant axis by default (mount-agnostic; rejects
     * a tilted vehicle), or a configured ARM_UP_AXIS to also reject sideways. */
    int   ax_up;
    float sign;
    if (ARM_UP_AXIS < 0) {
        ax_up = 0;
        for (int i = 1; i < 3; i++)
            if (fabsf(a[i]) > fabsf(a[ax_up])) ax_up = i;
        sign = (a[ax_up] >= 0.0f) ? 1.0f : -1.0f;
    } else {
        ax_up = ARM_UP_AXIS;
        sign  = ARM_UP_SIGN;
    }
    float up = sign * a[ax_up];
    float lat2 = 0.0f;
    for (int i = 0; i < 3; i++)
        if (i != ax_up) lat2 += a[i] * a[i];
    if (fabsf(up - 1.0f) >= ARM_MAX_TILT_G)                    return -8;  /* not vertical */
    if (lat2 >= ARM_MAX_LATERAL_G * ARM_MAX_LATERAL_G)         return -8;  /* excess lateral */

    if (!pyro_continuity(0))                    return -6;  /* no e-match / already open */
    if (g_fsm.chg.vbat_mv < ARM_MIN_VBAT_MV)    return -7;  /* pack too low to fly */

    g_fsm.armed = true;
    datalog_event(via_radio ? "ARM (radio)" : "ARM (console)");
    s_launch_acc_cnt = s_launch_baro_cnt = 0;
    fsm_set_state(ST_ARMED);        /* emits PKT_EVENT + state-name log */
    return 0;
}

void fsm_params_snapshot(params_t *p)
{
    p->main_alt_cm       = (uint32_t)(g_fsm.main_alt_m * 100.0f + 0.5f);
    p->apogee_timeout_ms = g_fsm.apogee_timeout_ms;
    p->last_lat_e7       = g_fsm.gps.lat_e7;   /* whatever fix we had at landing */
    p->last_lon_e7       = g_fsm.gps.lon_e7;
}

void fsm_params_apply(const params_t *p)
{
    g_fsm.main_alt_m = (float)p->main_alt_cm / 100.0f;
    /* Clamp floor is MAX_BURN_MS, NOT MIN_DROGUE_DELAY: apogee_timeout also
     * drives the fault-independent backup deploy, which fires regardless of
     * state (no burnout guard). A value below MAX_BURN_MS could deploy the
     * charge during powered ascent (app_config.h: "too early = deploy during
     * ascent"). Boost is always over by MAX_BURN_MS. */
    if (p->apogee_timeout_ms >= (uint32_t)MAX_BURN_MS &&
        p->apogee_timeout_ms <= 120000u)
        g_fsm.apogee_timeout_ms = p->apogee_timeout_ms;
    /* last_lat/lon are recovery-only; not applied to live state */
}
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

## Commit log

2026-06-09 Update Flight_controller_BOM.xlsx - BOM.csv
    [Flight_controller_BOM.xlsx - BOM.csv]
2026-07-10 Phase 1: IWDG watchdog (4.1 s) + reset-cause logging + wdtest command
    [app_main.c, console.c]
2026-07-10 Phase 2: radio robustness - defer lost DIO1 IRQs, level catch-up, TX-pending timeout, on-ground auto re-init
2026-07-10 Phase 3: measurement gating - Kalman innovation gate + isfinite, baro plausibility window, IMU rail-burst rejection
2026-07-10 Review fixes P1-3: IWDG kick at SD liveness point + drain cap, baro staleness surfaces as read failure, 12 kPa floor, wdtest ground-gate, wdg init rc in banner
    [app_main.c, bmp580.c, console.c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]
2026-07-10 log start prints datalog_init rc (pulled forward from Phase 4 to diagnose card-detect)
2026-07-10 Phase 4: fault flush, chg/gps health flags, PKT_EVENT queue, help additions
    - datalog_flush(): bounded ring drain (<=4 chunks, stops on error) +
    f_sync on both open files; called from fsm_fault() after the event
    log entry — files stay OPEN in FAULT (close is LANDED-only)
    - g_fsm.chg_ok/gps_ok captured from charger_init/gps_init rcs; status
    health line appends chg=/gps= (dashboard RE_HEALTH prefix unaffected)
    - protocol.h: FLAG_CHG_OK (1u<<4) + FLAG_GPS_OK (1u<<5), defines only;
    set in telem_build() and push_log_record()
    - telemetry: 8-entry drop-oldest PKT_EVENT queue replaces the
    !s_tx_pending direct send; drained one per poll ahead of cadence
    frames; packets built at drain ti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
    [app_main.c, console.c, datalog.c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]
2026-07-10 Phase 5: main_alt flash persistence (append-record store, sector 7)
    - App/param_store.c: 16-byte append-record slots in flash sector 7
    @ 0x08060000 (magic 0x5250, ver, len, main_alt_cm, seq, 2 spare,
    crc16 over first 14 bytes); load = highest CRC-valid seq; save =
    program next blank slot; erase-and-restart only when full or the
    tail is unappendable, with wdg_refresh before AND after the erase
    - Saves hard-gated to ST_INIT/ST_GROUND_IDLE/ST_LANDED (never in
    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
2026-07-10 Phase 6: 64 KB SD ring + DFU-magic relocation to 0x2003FFF0 (lockstep)
    - DFU handoff magic moved 0x2000FFF8 -> 0x2003FFF0 in the SAME commit
    as the ring growth: linker RAM LENGTH = 256K - 16 puts _estack at
    0x2003FFF0, reserving the top 16 bytes; dfu.c and SystemInit updated
    in lockstep (value/logic unchanged, address only)
    - LOG_RING_BYTES 8192 -> 65536 (~4.8 s of 200 Hz records) and
    LOG_CHUNK_BYTES 30 -> 60 records (4080 B ~= 8 SD sectors); the
    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
2026-07-10 Review fixes P4-6: event peek-then-advance with retry cap, SET_MAIN_ALT refused while armed + NAK on failed persist, ring index rebase before uint32 wrap, decoders learn chg/gps flag bits
    [datalog.c, decode_log.py, telem_decode.py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]
2026-07-10 Phase 7b+8: README, CLAUDE.md refresh (BOR encoding fix, TCXO confirmed, GPS wording), console contract tests, GS skeleton; dashboard radio-link chip + 6 health dots; radio irq-status probe
    [console.c, gs.ino, gs_pins.h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]
2026-07-10 SD auto-retry on ground (mirrors radio reinit): heals cold-plug power-up race and reseated cards without a reboot
    [app_config.h, app_main.c]
2026-07-10 Deck P1: canonical schema + LineIngest + FC-console/GS-JSON/replay sources (117 tests; live COM9 check deferred - board unplugged)
2026-07-10 Deck P3: session recorder (CSV round-trip + raw jsonl + rotation), HTTP API with token auth + peaks/T+ accumulator, flight_deck entry point with clean-shutdown chain (157 tests)
2026-07-10 Deck P4: full flight-ops UI (charts+timeline+tiles+rail+pyro ladder+audio, theme toggle) + review fixes: recorder session rotation, GS raw-capture on record toggle, fire-passcode masking event+jsonl,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
    [recorder.py, server.py, sources.py]
2026-07-10 Harden ground-state reinit paths: IWDG kick around radio/SD retries, BUSY guard on cmd_radio irq probe; deck serial write_timeout (wedged CDC blocked writes 6+ min)
2026-07-10 Repo cleanup + fixes: remove superseded CubeMX starter and KiCad junk; README spec corrections + bench status + Flight Deck screenshot; SD retry now edge-triggered on card insertion (root cause of th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
    [app_config.h, app_main.c, bmp580.c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]
2026-07-10 Deck: crosshair tracks the filtered trace (raw shown in parens) + apogee reference line on Altitude; firmware: led <r> <g> <b> bench-test command (WS2812 ready for the 5V rail); FIRMWARE.md LED legend
2026-07-10 Deck: end dots track the filtered trace (the visible fix for 'crosshairs follow invisible data') + baro temperature tile
2026-07-13 Avionics safety hardening, telemetry v3, and Flight Deck overhaul
    Firmware (STM32F722 FC)
    - Safety fixes: anti-replay ring (nonce==0 lockout + widened window);
    continuity/battery/vertical-orientation arm gates; gyro-cal stationarity;
    IMU freeze detect; self-heal ground FAULT; failed-deploy latch; `preflight`
    console checklist. ARM_UP_AXIS defaults to +Z (fail-closed mount knob).
    - Fault-independent backup deploy: fires the charge through ST_FAULT via a
    narrow pyro_fire_backup() path, fired-once, never on pad/after landing. Pyro
    pulse now only aborts on a GROUND disarm, so a fault never truncates an
    in-flight deploy or its retry.
    - Config persistence v2: widened flash slot (main_a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
    [app_config.h, app_main.c, bmp580.c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]
2026-07-13 Deck: satellite ground-track background (Esri World Imagery, offline-fallback)
    Server fetches one keyless Esri World Imagery tile centred on the pad (+/-500 m
    ground, Web-Mercator corrected) the first time a pad fix exists, caches it, and
    serves it locally at /sat so the browser makes no external request. Offline or
    no-fix -> sat.ready=false -> the client keeps the plain grid. GroundTrack.draw
    locks the view to the tile's +/-500 m extent, overlays it pad-centred and equal-
    aspect with the track + pad/apogee/current markers on top (theme halo for
    legibility) and an "Imagery (c) Esri" credit.
    Claude-Session: https://claude.a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
    [server.py]
2026-07-13 docs: reflect the safety + Flight Deck overhaul (README, FIRMWARE, CLAUDE)
    Update the docs to the current state: hardened arm gate, fault-independent
    backup deploy, flash config v2, servo dual-deploy, baro temp-comp, telemetry
    v3, new console commands (preflight/apogee/sleep), and the Flight Deck
    dashboard + tooling. Status framed as bench-verified (SIL/host tests + arm-gcc
    CI + flashed + preflight GO), NOT flight-tested; tune-before-flight knobs
    (ARM_UP_AXIS, per-motor apogee timer, servo endpoints, thresholds, Kalman
    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
2026-07-16 Status LED: rainbow pad-idle color, apogee/drogue vs main/descent split, bench controls
    - GROUND_IDLE (disarmed, GPS fix) now cycles a rainbow instead of solid
    green; APOGEE/DROGUE (cyan) is now visually distinct from MAIN/DESCENT
    (amber) instead of sharing one cyan block.
    - New console `led` subcommands for bench testing over USB: `bright`
    (global brightness scale), `cycle` (auto-step every flight state),
    `state <name>` (hold on one state), `effect solid|blink|breathe|
    strobe|rainbow` (custom patterns). All are pad+disarmed only, and
    led_poll() force-clears any active bench effect the instant `armed`
    goes true so a bench test can never mask the real ARMED indicator.
    - Fixed th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
    [commands.py, console.c]
2026-07-16 Prose cleanup: remove em-dashes across the repo, reword for natural phrasing
    Repo-wide sweep of comments, docstrings, docs, console/log strings, and
    UI text: replaced every em-dash with a colon, comma, parentheses, period,
    or connector word depending on context, instead of a bare hyphen swap.
    File-header comments (`file.c — description`) uniformly become
    `file.c: description`.
    No technical content changed (pin names, register values, thresholds,
    commands, protocol fields) — punctuation and light connective wording
    only. Console reply strings matched by tools/deck/commands.py's
    success/failure markers and by tests were checked before editing so no
    string-matching contract broke.
    Verifie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
    [app_config.h, app_main.c, bmp580.c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]
